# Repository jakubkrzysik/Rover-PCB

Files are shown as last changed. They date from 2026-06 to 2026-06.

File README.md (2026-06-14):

# Projekt PCB dla Łazika (Rover-PCB)

Repozytorium zawiera projekt płytki drukowanej w programie **KiCad 9.0** dla autonomicznego lub zdalnie sterowanego łazika (Rover). 

Projekt składa się z **dwóch fizycznych płytek** zaprojektowanych na jednym schemacie (`Rover_PCB.kicad_sch`) i w dwóch osobnych plikach PCB (`Rover_PCB.kicad_pcb` oraz `Rover_PCB _Power.kicad_pcb`), które łączą się ze sobą za pomocą złącza ATX oraz taśm FFC (Flat Flexible Cable).

---

## Główny Mikrokontroler

Sercem układu sterowania jest potężny mikrokontroler:
* **Model:** `STM32H743VITx` (obudowa LQFP-100)
* **Rdzeń:** ARM Cortex-M7 o taktowaniu do 480 MHz
* **Lokalizacja:** Lewa płytka (Main Board)

---

## Podział na Płytki

Projekt składa się z dwóch osobnych płytek drukowanych:

1. **Płytka Główna (Main Control & Driver Board - `Rover_PCB.kicad_pcb`):**
   * Zawiera mikrokontroler STM32H7,
   * Przetworniki analogowo-cyfrowe ADC `HX711` do pomiaru wagi (belek tensometrycznych),
   * Filtry i transceivery magistrali CAN (`SN65HVD230`),
   * Dwa zintegrowane sterowniki mostkowe H dla silników szczotkowych prądu stałego (`VNH5019A-E`),
   * Główne stabilizatory napięć (`AMS1117-3.3` o wydajności do 800 mA dla logiki, `LM2596S-5` o wydajności do 3 A dla linii 5V oraz `LM2596S-12` o wydajności do 3 A dla linii 12V),
   * Porty wejściowe zasilania wysokoprądowego (`XT90` 24V i 48V) oraz bezpośrednie złącza interfejsowe kontrolera (USB-C, RJ45),
   * **Układy MOSFET (low-side):** 10 kluczy MOSFET (2x IRLZ44N w obudowie TO-220 oraz 8x AO3400A w obudowie SOT-23) służących do kluczowania masy dla oświetlenia zewnętrznego, diody statusowej RGY oraz buzzera.

2. **Płytka Zasilania i Interfejsów (Power Distribution & Interface Board - `Rover_PCB _Power.kicad_pcb`):**
   * Działa jako panel dystrybucji zasilania i hub połączeń interfejsów,
   * Posiada złącza silników, serwomechanizmów, interfejsów komunikacyjnych (Magistrala CAN, UART), czujników temperatury (NTC) oraz wejścia belek tensometrycznych (Load Cells),
   * Dystrybuuje zasilanie przez złącza wysokoprądowe `XT60` i `XT30` o napięciach: 12V, 24V oraz 48V,
   * Zawiera diody LED oświetlenia zewnętrznego, wielokolorową diodę statusową RGY, buzzer oraz fizyczne porty do programowania (ST-LINK) i przycisk awaryjny (Safety Button).

### Połączenia Międzypłytkowe (Inter-board Connections)
Tablice łączą się ze sobą bezpośrednio za pomocą czterech mostków kablowych:
* **ATX (J45 na Głównej $\leftrightarrow$ J48 na Zasilania):** Złącze Molex Mini-Fit Jr 24-pin przesyłające główne szyny zasilające (3.3V, 5V, 12V, 24V, 48V, GND), wyjścia prądowe sterowników silników (`OUTA1`/`OUTB1`, `OUTA2`/`OUTB2`) oraz linie sterowania oświetleniem przednim LED (`PC6_OUT` i `PB9_OUT`).
* **FFC 30-pin (J46 na Głównej $\leftrightarrow$ J49 na Zasilania):** Przesyłanie sygnałów logicznych (sygnały PWM serw, interfejsy UART, linie CAN, sygnały pomiarowe z HX711) oraz linii sterowania tylnym oświetleniem LED, diodą statusową i buzzerem (`PB0_OUT`, `PB1_OUT`, `PB5_OUT`, `PB8_OUT`, `PC7_OUT`, `PC8_OUT`, `PC9_OUT`, `PC10_OUT`).
* **FFC 20-pin (J47 na Głównej $\leftrightarrow$ J50 na Zasilania):** Przesyłanie sygnałów z pozostałych belek tensometrycznych oraz linii pomiarowych czujników temperatury NTC.
* **FFC 6-pin (J72 na Głównej $\leftrightarrow$ J71 na Zasilania):** Przedłużenie złącza programatora ST-LINK (SWD) na płytkę zasilania, co umożliwia debugowanie i programowanie urządzenia poprzez wyprowadzone tam złącze `J37` bez konieczności rozpinania konstrukcji.

---

## Specyfikacja Złączy

Poniższa lista opisuje przeznaczenie wszystkich złączy na obu płytkach oraz sposób sterowania powiązanymi urządzeniami.

### 1. Płytka Główna (Sterowanie i Sterowniki - `Rover_PCB.kicad_pcb`)

| Złącze | Nazwa w schemacie | Typ Złącza | Przeznaczenie |
| :--- | :--- | :--- | :--- |
| **J1** | `XT90_24V_IN` | XT90 (Męskie, kątowe) | Główne wejście zasilania 24V z akumulatora (zabezpieczone bezpiecznikiem F1 - 15A). Zasila regulatory step-down (5V, 12V) oraz mostki silników VNH5019A-E. |
| **J35** | `XT90_48V_IN` | XT90 (Męskie, kątowe) | Wejście wysokiego napięcia zasilania 48V do celów dystrybucyjnych (zabezpieczone bezpiecznikiem F2 - 1A na odczepie pomiarowym). |
| **J43** | `XT90_24V_OUT` | XT90 (Męskie, kątowe) | Wyjście zasilania 24V (przelotka bezpośrednia z J1). |
| **J44** | `XT90_48V_OUT` | XT90 (Męskie, kątowe) | Wyjście zasilania 48V (przelotka bezpośrednia z J35). |
| **J19** | `RJ45` | RJ45 | Złącze interfejsu sieciowego. **Uwaga:** Piny 1 i 2 są połączone z wyjściami mostka H Brushed_Motor2 (`OUTA2`/`OUTB2`), a piny 3 i 4 z zasilaniem 5V/GND, co umożliwia sterowanie zewnętrznym silnikiem lub modułem za pomocą kabla Ethernet. |
| **J38** | `USB_C_Receptacle` | USB-C 16-pin | Port USB-C podłączony bezpośrednio do linii D+/D- mikrokontrolera (komunikacja USB 2.0). |
| **J45** | `ATX` | Molex Mini-Fit Jr 2x12 | Interfejs zasilania, mostków silnikowych oraz przedniego oświetlenia, łączący z płytką zasilania. |
| **J46** | `FFC_30` | FFC Socket 30-pin (1.0mm) | Port taśmy sygnałowej i oświetlenia tylnego/statusowego, łączący z płytką zasilania. |
| **J47** | `FFC_20` | FFC Socket 20-pin (1.0mm) | Port taśmy sygnałowej dla belek tensometrycznych i czujników NTC, łączący z płytką zasilania. |
| **J72** | `FFC_6` | FFC Socket 6-pin (1.0mm) | Port taśmy interfejsu SWD (ST-LINK), łączący z płytką zasilania. |
| **J75** | `TEST_PAD 5V` | Pad testowy (1.5mm) | Punkt testowy napięcia 5V na płytce głównej. |
| **J76** | `TEST_PAD GND` | Pad testowy (1.5mm) | Punkt testowy masy (GND) na płytce głównej. |
| **J77** | `TEST_PAD 24V` | Pad testowy (1.5mm) | Punkt testowy napięcia 24V na płytce głównej. |
| **J78** | `TEST_PAD 3.3V` | Pad testowy (1.5mm) | Punkt testowy napięcia 3.3V na płytce głównej. |
| **J79** | `TEST_PAD 12V` | Pad testowy (1.5mm) | Punkt testowy napięcia 12V na płytce głównej. |

### 2. Płytka Zasilania (Złącza Wykonawcze i Dystrybucja Zasilania - `Rover_PCB _Power.kicad_pcb`)

#### Złącza Połączeniowe z Płytką Główną:
* **J48:** ATX (Molex Mini-Fit 24-pin) - interfejs szyn zasilających i wyjść silników szczotkowych/oświetlenia przedniego
* **J49:** FFC 30-pin - główna taśma sygnałowa (sterowanie serw, UART, CAN, ADCs, oświetlenie tylne/statusowe)
* **J50:** FFC 20-pin - pomocnicza taśma sygnałowa (belki tensometryczne, sensory NTC)
* **J71:** FFC 6-pin - taśma interfejsu programowania SWD (ST-LINK)

#### Port Programatora i Debuggera:
* **J37 (`STLINK`):** Złącze kołkowe 1x05 na płytce zasilania służące do bezpośredniego podpięcia programatora SWD bez konieczności rozkręcania obudowy łazika. Sygnały: `+3.3V`, `GND`, `SWDIO`, `SWCLK`, `NRST`.

#### Sterowanie Silnikami Szczotkowymi (DC Brushed Motors):
Oba złącza silników są zasilane za pośrednictwem złącza ATX z lewej płytki, gdzie zainstalowane są dedykowane układy H-bridge **VNH5019A-E** (obsługujące prąd ciągły do 12A/szczytowo 30A).
* **J2 (`Brushed_Motor1`):** Podłączenie silnika DC 1 (Linie `/OUTA1` i `/OUTB1` ze sterownika U5).
* **J3 (`Brushed_Motor2`):** Podłączenie silnika DC 2 (Linie `/OUTA2` i `/OUTB2` ze sterownika U6).

#### Serwomechanizmy (Servo Outputs):
Złącza 3-pinowe (GND, zasilanie +5V z LM2596, sygnał PWM) służące do pozycjonowania ramion, chwytaków bądź kamer. Sterowanie odbywa się bezpośrednio za pomocą wbudowanych w STM32 układów zegarowych (Timer PWM):
* **J20 (`Servo1`):** Sterowanie PWM z pinu **`PE9`** (TIM1_CH1)
* **J21 (`Servo2`):** Sterowanie PWM z pinu **`PE11`** (TIM1_CH2)
* **J22 (`Servo3`):** Sterowanie PWM z pinu **`PE13`** (TIM1_CH3)
* **J23 (`Servo4`):** Sterowanie PWM z pinu **`PE14`** (TIM1_CH4)
* **J24 (`Servo5`):** Sterowanie PWM z pinu **`PD14`** (TIM4_CH3)
* **J25 (`Servo6`):** Sterowanie PWM z pinu **`PD15`** (TIM4_CH4)
* **J26 (`Servo7`):** Sterowanie PWM z pinu **`PA6`** (TIM3_CH1)
* **J27 (`Servo8`):** Sterowanie PWM z pinu **`PA7`** (TIM3_CH2)

#### Magistrala CAN (CAN Bus Distribution):
Na płytce zintegrowano magistralę CAN, co pozwala na łączenie urządzeń zewnętrznych (np. sterowników silników BLDC, enkoderów, sensorów). Wszystkie te złącza dzielą wspólne linie `/CANH` i `/CANL` obsługiwane przez transceivery `SN65HVD230` z lewej płytki.
Złącza są typu JST EH 4-pin (GND, CANH, CANL, zasilanie) o różnych napięciach na pinie zasilającym:
* **J11 - J15 (`CAN_S1 - CAN_S5`):** Linia zasilająca podłączona do napięcia **`+12V`**.
* **J16 - J17 (`CAN_S6 - CAN7`):** Linia zasilająca podłączona do napięcia **`+24V`**.
* **J18 (`CAN8`):** Linia zasilająca podłączona do napięcia **`+48V`** (dla najbardziej obciążonych/zewnętrznych modułów).

#### Złącza Komunikacji UART:
* **J28 (`UART1`):** Podłączone do portu UART1 mikrokontrolera (linie `/TX1` i `/RX1`, zasilanie `+5V`, `GND`).
* **J29 (`UART2`):** Podłączone do portu UART2 mikrokontrolera (linie `/TX2` i `/RX2`, zasilanie `+5V`, `GND`).

#### Czujniki Belki Tensometrycznej (Load Cells):
Układ obsługuje do 4 czujników nacisku/wagi. Każde złącze to standardowe wyprowadzenie 4-pinowe (zasilanie analogowe AVDD, różnicowe wejścia sygnałowe INA+/INA- oraz GND). Pomiary są filtrowane i cyfryzowane przez przetworniki HX711 (U9-U12) znajdujące się na lewej płytce.
* **J39 (`Load_Cell1`):** Podłączone do przetwornika `U9` (linie `/AVDD`, `/INA+`, `/INA-` przesyłane przez FFC 30-pin).
* **J40 (`Load_Cell2`):** Podłączone do przetwornika `U10` (linie `/AVDD1`, `/INA1+`, `/INA1-` przesyłane przez FFC 30-pin).
* **J41 (`Load_Cell3`):** Podłączone do przetwornika `U11` (linie `/AVDD2`, `/INA2+`, `/INA2-` przesyłane przez FFC 20-pin).
* **J42 (`Load_Cell4`):** Podłączone do przetwornika `U12` (linie `/AVDD3`, `/INA3+`, `/INA3-` przesyłane przez FFC 20-pin).

#### Czujniki Temperatury NTC:
Służą do monitorowania temperatury krytycznych elementów konstrukcji (akumulatory, silniki). Termistory NTC tworzą dzielnik napięcia (zasilanie +3.3V, wyjście na ADC i GND). Pomiar odbywa się bezpośrednio za pomocą kanałów przetwornika ADC mikrokontrolera STM32:
* **J51 (`NTC1`):** Podłączony do pinu analogowego **`PC0`** (przez FFC)
* **J52 (`NTC2`):** Podłączony do pinu analogowego **`PC1`** (przez FFC)
* **J53 (`NTC3`):** Podłączony do pinu analogowego **`PC2`** (przez FFC)
* **J54 (`NTC4`):** Podłączony do pinu analogowego **`PC3`** (przez FFC)

#### Diody Sygnalizacyjne LED (Oświetlenie / Status):
Wszystkie diody LED znajdują się na płytce zasilania. Są zasilane z napięcia +12V (oświetlenie zewnętrzne) lub +24V (dioda statusowa J10) i sterowane od strony masy (low-side) za pomocą kluczy MOSFET typu N zlokalizowanych na płytce głównej:

* **Oświetlenie Przednie (Klucze MOSFET THT - IRLZ44N w obudowie TO-220):**
  * **J8 (`LED_F_R` - Przód Prawy):** Sterowane z pinu **`PB9`** (klucz Q5, sygnał `PB9_OUT`)
  * **J9 (`LED_F_L` - Przód Lewy):** Sterowane z pinu **`PC6`** (klucz Q6, sygnał `PC6_OUT`)

* **Oświetlenie Tylne (Klucze MOSFET SMD - AO3400A w obudowie SOT-23):**
  * **J4 (`LED_R_LL` - Tylny Lewy Zewnętrzny):** Sterowane z pinu **`PB0`** (klucz Q15, sygnał `PB0_OUT`)
  * **J5 (`LED_R_LR` - Tylny Lewy Wewnętrzny):** Sterowane z pinu **`PB1`** (klucz Q14, sygnał `PB1_OUT`)
  * **J6 (`LED_R_RR` - Tylny Prawy Zewnętrzny):** Sterowane z pinu **`PB5`** (klucz Q13, sygnał `PB5_OUT`)
  * **J7 (`LED_R_RL` - Tylny Prawy Wewnętrzny):** Sterowane z pinu **`PB8`** (klucz Q12, sygnał `PB8_OUT`)

* **Sygnalizacja Systemowa (Klucze MOSFET SMD - AO3400A w obudowie SOT-23):**
  * **J10 (`LED_RGY_B` - Trójkolorowa dioda statusu RGY + Buzzer):** Złącze zasilane z napięcia +24V, sterowane z czterech pinów:
    * Pin **`PC7`** (kolor czerwony LED - klucz Q11, sygnał `PC7_OUT`)
    * Pin **`PC8`** (kolor zielony LED - klucz Q16, sygnał `PC8_OUT`)
    * Pin **`PC9`** (kolor żółty LED - klucz Q17, sygnał `PC9_OUT`)
    * Pin **`PC10`** (Buzzer - klucz Q18, sygnał `PC10_OUT`)

#### Dystrybucja Zasilania Zewnętrznego (Power Distribution Ports):
Wyjścia zasilania służą do zasilania urządzeń o dużym poborze prądu.
* **Szyna 24V:**
  * `J55`, `J56`, `J57`, `J58` (złącza XT60)
  * `J59`, `J60`, `J61`, `J62` (złącza XT30)
* **Szyna 48V:**
  * `J63`, `J64` (złącza XT60)
  * `J67`, `J68` (złącza XT30)
* **Szyna 12V** (zasilana ze stabilizatora LM2596S-12):
  * `J65`, `J66` (złącza XT60)
  * `J69`, `J70` (złącza XT30)
* **Złącza Śrubowe (Terminal Blocks):**
  Umożliwiają bezpośrednie wyprowadzenie stałego napięcia (VOUT i GND) dla mniejszych odbiorników:
  * `J30` -> 3.3V
  * `J31` -> 5.0V (ze stabilizatora LM2596S-5)
  * `J32` -> 12.0V (ze stabilizatora LM2596S-12)
  * `J33` -> 24.0V (bezpośrednio z XT90_24V_IN)
  * `J34` -> 48.0V (bezpośrednio z XT90_48V_IN)

#### Monitoring Akumulatora (Battery Measurement):
* **J73 (`BAT1`):** Podłączenie pojedynczej celi / baterii do monitorowania napięcia.
* **J74 (`BAT_TOTAL`):** Podłączenie pełnego pakietu do monitorowania sumarycznego napięcia.
* **J36 (`Safety_Button`):** Złącze pod przycisk awaryjny (np. grzybek E-STOP), podłączone do pinu **`PE15`** mikrokontrolera STM32.

---

## Parametry Fizyczne PCB i Klasy Połączeń

Obie płytki w projekcie (Płytka Główna oraz Płytka Zasilania) zostały zaprojektowane z określonym stackupem i regułami szerokości połączeń w programie KiCad.

### 1. Ułożenie Warstw (Stackup)
Płytka Główna (`Rover_PCB.kicad_pcb`) oraz Płytka Zasilania (`Rover_PCB _Power.kicad_pcb`) posiadają identyczny, profesjonalny **4-warstwowy** stackup o łącznej grubości laminatu **1.6 mm** ze standardową grubością miedzi **35 µm (1 oz)** na wszystkich warstwach miedzianych:
* **F.Cu (Top)** — Zewnętrzna górna warstwa sygnałowa/mieszana.
* **In1.Cu (Internal 1)** — Wewnętrzna warstwa sygnałowo-zasilająca.
* **In2.Cu (Internal 2)** — Wewnętrzna dedykowana warstwa zasilania (szyna power).
* **B.Cu (Bottom)** — Zewnętrzna dolna warstwa sygnałowa/mieszana.

Dielektryk między warstwami zewnętrznymi a wewnętrznymi stanowi prepreg FR4 o grubości **0.1 mm**, a rdzeń wewnętrzny (core) ma grubość **1.24 mm**.

### 2. Klasy Netów (Net Classes)
W obu projektach skonfigurowano analogiczne dedykowane klasy połączeń dopasowane do obciążalności prądowej oraz typu sygnałów:

| Klasa Połączeń | Szerokość ścieżki | Odstęp (Clearance) | Średnica przelotki | Wiercenie przelotki | Zastosowanie / Przypisane Połączenia |
| :--- | :---: | :---: | :---: | :---: | :--- |
| **`Default`** | **0.20 mm** | 0.20 mm | 0.60 mm | 0.30 mm | Sygnały logiczne mikrokontrolera, GPIO, szyna `/+3.3V` |
| **`CAN`** | **0.25 mm** | 0.20 mm | 0.60 mm | 0.30 mm | Różnicowe linie magistrali CAN (`/CANH`, `/CANL`, `/CANH_ETH`, `/CANL_ETH`) |
| **`GND`** | **0.50 mm** | 0.20 mm | 0.80 mm | 0.40 mm | Masa główna układu (`/GND`) |
| **`Power10A`** | **4.00 mm** | 0.30 mm | 1.50 mm | 0.80 mm | Główna szyna wysokoprądowa zasilania `/+48V` |
| **`Power5A`** | **2.00 mm** | 0.30 mm | 1.20 mm | 0.60 mm | Szyny zasilania `/+12V` oraz `/+24V` |
| **`Power1A`** | **0.50 mm** | 0.20 mm | 0.80 mm | 0.40 mm | Szyna zasilania logiki `/+5V` |
| **`USB_FS`** | **0.20 mm** | 0.15 mm | 0.60 mm | 0.30 mm | Sygnały różnicowe portu USB-C (`/D-`, `/D+`) |

### 3. Trasowanie i Szerokości Ścieżek na Płytkach

#### A. Płytka Główna (`Rover_PCB.kicad_pcb`)
* **Trasy wysokoprądowe:** Wytrasowane z szerokościami **4.00 mm** (linia `+48V`) oraz **2.00 mm** (linie `+12V` i `+24V`).
* **Zasilanie logiki i masa:** Wytrasowane szerokością **0.50 mm** (dystrybucja masy `/GND` oraz szyna `+5V`).
* **Sygnały CAN:** Szerokość ścieżek wynosi **0.25 mm**.
* **Sygnały domyślne:** Ścieżki sygnałowe mikrokontrolera STM32 mają szerokość **0.20 mm**.
* **Ścieżki niestandardowe (Custom/Ręczne):**
  * **0.10 mm** (5 segmentów) – użyte w linii **`/RX2`** na warstwie górnej w celu wyprowadzenia trasy z gęstego obszaru wyprowadzeń MCU.
  * **1.00 mm** (5 segmentów) – użyte lokalnie w masie `/GND` oraz w linii `Net-(J1-Pin_1)`.
  * **1.1018 mm** oraz **1.5998 mm** – lokalne przewężenia (neckdown) na linii zasilania `+24V`.

#### B. Płytka Zasilania (`Rover_PCB _Power.kicad_pcb`)
* **Trasy wysokoprądowe:** Wytrasowane z szerokościami **4.00 mm** (linia `+48V` - 25 segmentów) oraz **2.00 mm** (linie `+12V` - 64 segmenty, `+24V` - 43 segmenty, `+48V` - 6 segmentów).
* **Zasilanie logiki i masa:** Wytrasowane szerokością **0.50 mm** (dystrybucja linii `/GND` - 19 segmentów oraz szyna `+5V` - 22 segmenty).
* **Sygnały CAN:** Wytrasowane ścieżkami o szerokości **0.25 mm** (łącznie 73 segmenty dla `/CANH` i `/CANL`).
* **Sygnały domyślne:** Wytrasowane ścieżkami o szerokości **0.20 mm** (łącznie 397 segmentów).
* **Ścieżki niestandardowe i przewężenia (Custom/Ręczne):**
  * **1.6998 mm** (3 segmenty) – w liniach `+12V` oraz `+48V`.
  * **1.7018 mm** (2 segmenty) – w linii `+12V`.
  * **2.6998 mm** (2 segmenty) – w linii `+48V`.
  * *Uwaga: Główne przesyłanie wysokich prądów na Płytce Zasilania jest dodatkowo wspierane przez rozległe wylewki miedziane (zones) na warstwach zewnętrznych i wewnętrznych.*

---

## Wykaz Części (BOM) do Złożenia Płytki

Poniższa tabela zawiera kompletny wykaz wszystkich elementów niezbędnych do zmontowania płytek (Płytki Głównej oraz Płytki Zasilania).
Każdy element został powiązany z konkretnym, pasującym footprintem w programie KiCad, co gwarantuje poprawność montażu po zakupie.

| Lp. | Oznaczenia na schemacie (Ref) | Wartość/Nazwa | Obudowa / Nazwa Footprintu (KiCad) | Sugerowany Numer Części (MPN) | Opis / Uwagi | Ilość |
| :--- | :--- | :--- | :--- | :--- | :--- | :--- |
| 1 | D4, D5 | D_Zener | `DO-201 (THT, raster 12.7 mm)` | **1N5349BG** | Dioda Zenera 12V, 5W | 2 |
| 2 | D1, D2 | 1N5822 | `DO-201AD (THT, raster 15.24 mm)` | **1N5822-E3/54** | Dioda Schottky 40V, 3A (THT) | 2 |
| 3 | U2 | AMS1117-3.3 | `SOT-223-3` | **AMS1117-3.3** | Stabilizator liniowy LDO 3.3V, 1A | 1 |
| 4 | Q11, Q12, Q13, Q14, Q15, Q16, Q17, Q18 | AO3400A | `SOT-23 (SMD)` | **AO3400A** | Tranzystor N-MOSFET (30V, 5.7A, Rds=19mOhm) | 8 |
| 5 | J59, J60, J61, J62, J67, J68, J69, J70 | XT30_12V_OUT | `Amass XT30U-F (pionowe żeńskie PCB)` | **Amass XT30U-F** | Złącze wysokoprądowe XT30 żeńskie pionowe na płytkę | 8 |
| 6 | J55, J56, J57, J58, J63, J64, J65, J66 | XT60_24V_OUT | `Amass XT60-M (pionowe męskie PCB)` | **Amass XT60-M** | Złącze wysokoprądowe XT60 męskie pionowe na płytkę | 8 |
| 7 | J1, J35, J43, J44 | XT90_48V_OUT | `Amass XT90PW-M (kątowe męskie PCB)` | **Amass XT90PW-M** | Wysokoprądowe złącze XT90 męskie kątowe na płytkę | 4 |
| 8 | J38 | USB_C_Receptacle_USB2.0_16P | `USB-C 16-pin GCT USB4105 (poziome)` | **GCT USB4105-GF-A** | Gniazdo USB 2.0 typu C, 16-pin, montaż mieszany SMT+THT | 1 |
| 9 | U9, U10, U11, U12 | HX711 | `SOIC-16 (szerokość 3.9 mm, raster 1.27 mm)` | **HX711** | 24-bitowy przetwornik ADC dla belek tensometrycznych | 4 |
| 10 | Q5, Q6 | IRLZ44N | `TO-220-3 (pionowy)` | **IRLZ44NPBF** | Tranzystor N-MOSFET logic-level (55V, 47A, Rds=22mOhm) | 2 |
| 11 | J2, J3, J4, J5, J6, J7, J8, J9, J36, J73, J74 | LED_R_RL | `JST EH 2-pin vertical (raster 2.50 mm)` | **JST B2B-EH-A(LF)(SN)** | Złącze JST serii EH, 2-pinowe pionowe męskie | 11 |
| 12 | J51, J52, J53, J54 | NTC1 | `JST EH 3-pin vertical (raster 2.50 mm)` | **JST B3B-EH-A(LF)(SN)** | Złącze JST serii EH, 3-pinowe pionowe męskie | 4 |
| 13 | J11, J12, J13, J14, J15, J16, J17, J18, J28, J29, J39, J40, J41, J42 | CAN7 | `JST EH 4-pin vertical (raster 2.50 mm)` | **JST B4B-EH-A(LF)(SN)** | Złącze JST serii EH, 4-pinowe pionowe męskie | 14 |
| 14 | J10 | LED_RGY_B | `JST EH 5-pin vertical (raster 2.50 mm)` | **JST B5B-EH-A(LF)(SN)** | Złącze JST serii EH, 5-pinowe pionowe męskie | 1 |
| 15 | U4 | LM2596S-12 | `TO-263-5 (D2PAK)` | **LM2596S-12/NOPB** | Przetwornica obniżająca step-down impulsowa 12V, 3A | 1 |
| 16 | U3 | LM2596S-5 | `TO-263-5 (D2PAK)` | **LM2596S-5.0/NOPB** | Przetwornica obniżająca step-down impulsowa 5V, 3A | 1 |
| 17 | F1 | 15A | `Bezpiecznik samochodowy Mini Blade (lutowany w płytkę)` | **Littelfuse 0297015.WXNV + uchwyt Littelfuse 01530007Z** | Bezpiecznik Mini Blade 15A z uchwytem lutowanym | 1 |
| 18 | F2 | 1A | `Littelfuse 395 Series (raster 5.08 mm)` | **Littelfuse 39511000000** | Bezpiecznik miniaturowy TR5 1A, zwłoczny | 1 |
| 19 | Taśma-FFC-6 | Taśma FFC 6-pin | `Taśma FFC 6-pin (raster 1.0 mm, dł. 152 mm, typ A)` | **Molex 15167-0211 (lub zamiennik 6-pin, raster 1.0mm)** | Elastyczny przewód płaski FFC łączący gniazda J71 i J72 (linie SWD ST-Link) | 1 |
| 20 | Taśma-FFC-20 | Taśma FFC 20-pin | `Taśma FFC 20-pin (raster 1.0 mm, dł. 152 mm, typ A)` | **Molex 15167-0355 (lub zamiennik 20-pin, raster 1.0mm)** | Elastyczny przewód płaski FFC łączący gniazda J47 i J50 | 1 |
| 21 | Taśma-FFC-30 | Taśma FFC 30-pin | `Taśma FFC 30-pin (raster 1.0 mm, dł. 152 mm, typ A)` | **Molex 15167-0487 (lub zamiennik 30-pin, raster 1.0mm)** | Elastyczny przewód płaski FFC łączący gniazda J46 i J49 | 1 |
| 22 | J71, J72 | FFC | `FFC/FPC 6-pin, raster 1.00 mm (poziome)` | **Molex 200528-0060** | Gniazdo taśmy elastycznej FFC 6-pin, poziome SMT | 2 |
| 23 | J47, J50 | FFC | `FFC/FPC 20-pin, raster 1.00 mm (poziome)` | **Molex 200528-0200** | Gniazdo taśmy elastycznej FFC 20-pin, poziome SMT | 2 |
| 24 | J46, J49 | Conn_01x30_Socket | `FFC/FPC 30-pin, raster 1.00 mm (poziome)` | **Molex 200528-0300** | Gniazdo taśmy elastycznej FFC 30-pin, poziome SMT | 2 |
| 25 | J45, J48 | ATX | `Molex Mini-Fit Jr 5566-24A (2x12, raster 4.2 mm)` | **Molex 39-28-1243 (lub 39-28-8240)** | Złącze ATX 24-pin pionowe męskie | 2 |
| 26 | L1, L2 | 30u | `MS42 (SMD, Neosid Ms42)` | **Neosid MS42 30uH** | Dławik/cewka indukcyjna SMD 30µH | 2 |
| 27 | J19 | RJ45 | `RJ45 Jack Ninigi GE` | **Ninigi RJ45-GE (lub Molex 95501-2881)** | Gniazdo Ethernet RJ45 8p8c THT | 1 |
| 28 | J37 | STLINK | `PinSocket 1x05 vertical, raster 2.54 mm` | **PPTC051LFBN-RC (Sullins)** | Gniazdo kołkowe (żeńskie) 1x5, raster 2.54mm | 1 |
| 29 | SW1 | SW_Push | `Tactile Switch 6x6 mm, wys. 4.3 mm (THT)` | **PTS645TL43-2 LFS** | Przycisk monostabilny (tact switch) THT | 1 |
| 30 | C5, C6 | 2.2u | `Radialny THT (Ø4.0 mm, raster 1.50 mm)` | **Panasonic ECE-A1HN2R2UB** | Kondensator elektrolityczny bipolarny 2.2µF, 50V | 2 |
| 31 | C1, C2, C3, C4 | 220u | `Radialny THT (Ø5.0 mm, raster 2.50 mm)` | **Panasonic EEU-FR1E221** | Kondensator elektrolityczny niskoimpedancyjny 220µF, 25V | 4 |
| 32 | J30, J31, J32, J33, J34 | 48V | `Phoenix MKDS-1.5-2 (raster 5.08 mm)` | **Phoenix Contact 1715721 (MKDS 1,5/2-5,08)** | Złącze śrubowe (terminal block) 2-pin do druku | 5 |
| 33 | J20, J21, J22, J23, J24, J25, J26, J27 | Servo8 | `PinHeader 1x03 vertical, raster 2.54 mm` | **Pin Header 1x03 vertical (2.54mm pitch)** | Listwa kołkowa (goldpin) 1x3, raster 2.54mm | 8 |
| 34 | R1, R4, R5, R6, R7, R8, R9, R10, R11, R12, R13, R14, R15, R16, R22 | 10k | `SMD 0603 (1608 Metric)` | **RC0603FR-0710KL** | Rezystor SMD 0603, tolerancja 1%, wartość 10k | 15 |
| 35 | R17-Terminator1 | 120 | `SMD 0603 (1608 Metric)` | **RC0603FR-07120RL** | Rezystor SMD 0603, tolerancja 1%, wartość 120 | 1 |
| 36 | R17 | 330 | `SMD 0603 (1608 Metric)` | **RC0603FR-07330RL** | Rezystor SMD 0603, tolerancja 1%, wartość 330 | 1 |
| 37 | R19, R21 | 3.9k | `SMD 0603 (1608 Metric)` | **RC0603FR-073K9L** | Rezystor SMD 0603, tolerancja 1%, wartość 3.9k | 2 |
| 38 | R18, R20 | 47k | `SMD 0603 (1608 Metric)` | **RC0603FR-0747KL** | Rezystor SMD 0603, tolerancja 1%, wartość 47k | 2 |
| 39 | R2, R3 | 5.1k | `SMD 0603 (1608 Metric)` | **RC0603FR-075K1L** | Rezystor SMD 0603, tolerancja 1%, wartość 5.1k | 2 |
| 40 | D6 | SD36_SOD323 | `SOD-323 (SMD)` | **SD36-01FTG** | Dioda TVS jedno-kierunkowa 36V, obudowa SOD-323 | 1 |
| 41 | U7, U8 | SN65HVD230 | `SOIC-8 (szerokość 3.9 mm, raster 1.27 mm)` | **SN65HVD230D** | Transceiver CAN, zasilany napięciem 3.3V | 2 |
| 42 | U1 | STM32H743VITx | `LQFP-100 (14x14 mm, raster 0.5 mm)` | **STM32H743VIT6** | Mikrokontroler ARM Cortex-M7, 2MB Flash, 1MB RAM | 1 |
| 43 | U5, U6 | VNH5019A-E | `MultiPowerSO-30 (STMicroelectronics)` | **VNH5019ATR-E** | Mostek H - sterownik silników DC szczotkowych (30A/41V) | 2 |
| 44 | D3 | LED | `LED 5.0 mm (THT)` | **WP7113ID** | Dioda LED czerwona 5mm (THT) | 1 |
| 45 | C7, C8 | 10n | `SMD 0603 (1608 Metric)` | **Yageo CC0603KRX7R9BB103** | Kondensator ceramiczny MLCC SMD 0603 X7R 10nF 50V | 2 |
| 46 | C9, C10 | 18pF | `SMD 0603 (1608 Metric)` | **CC0603JRNPO9BN180** | Kondensator ceramiczny MLCC SMD 0603 NP0 18pF 50V (dla rezonatora Y2) | 2 |
| 47 | Y2 | 8MHz | `Crystal:Crystal_SMD_3225-4Pin_3.2x2.5mm_HandSoldering` | **NX3225GD-8.000M-STD-CRA-3** | Rezonator kwarcowy SMD 3.2x2.5mm (dla STM32H7) | 1 |

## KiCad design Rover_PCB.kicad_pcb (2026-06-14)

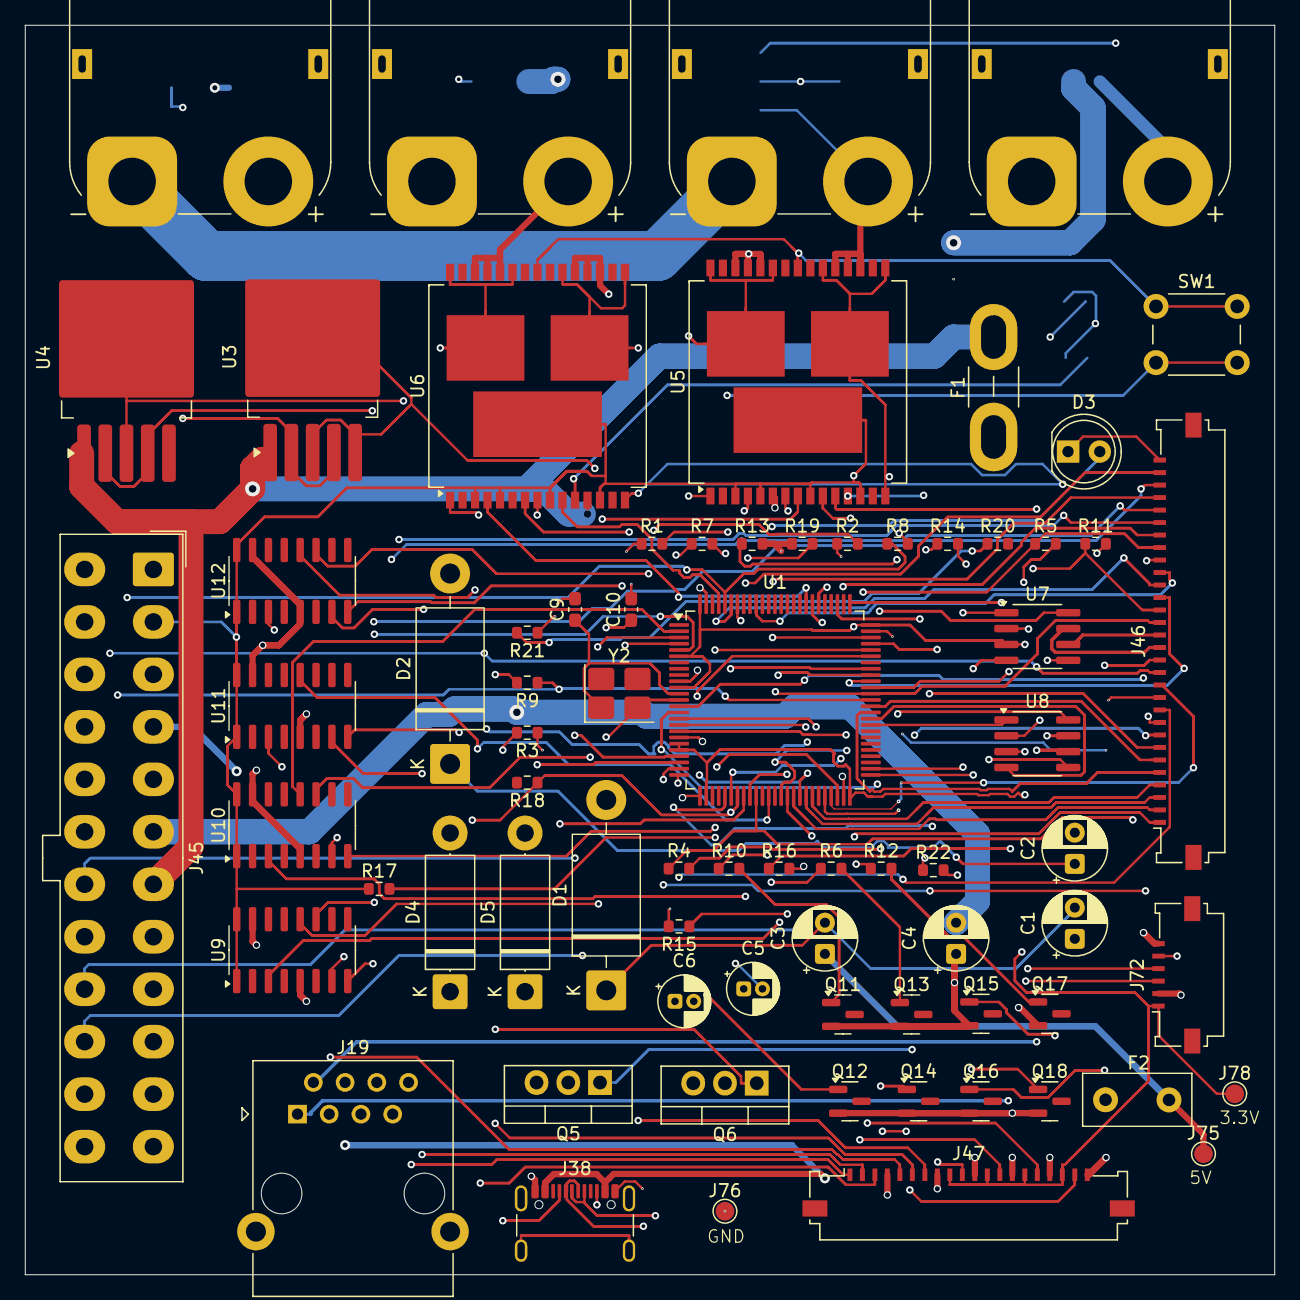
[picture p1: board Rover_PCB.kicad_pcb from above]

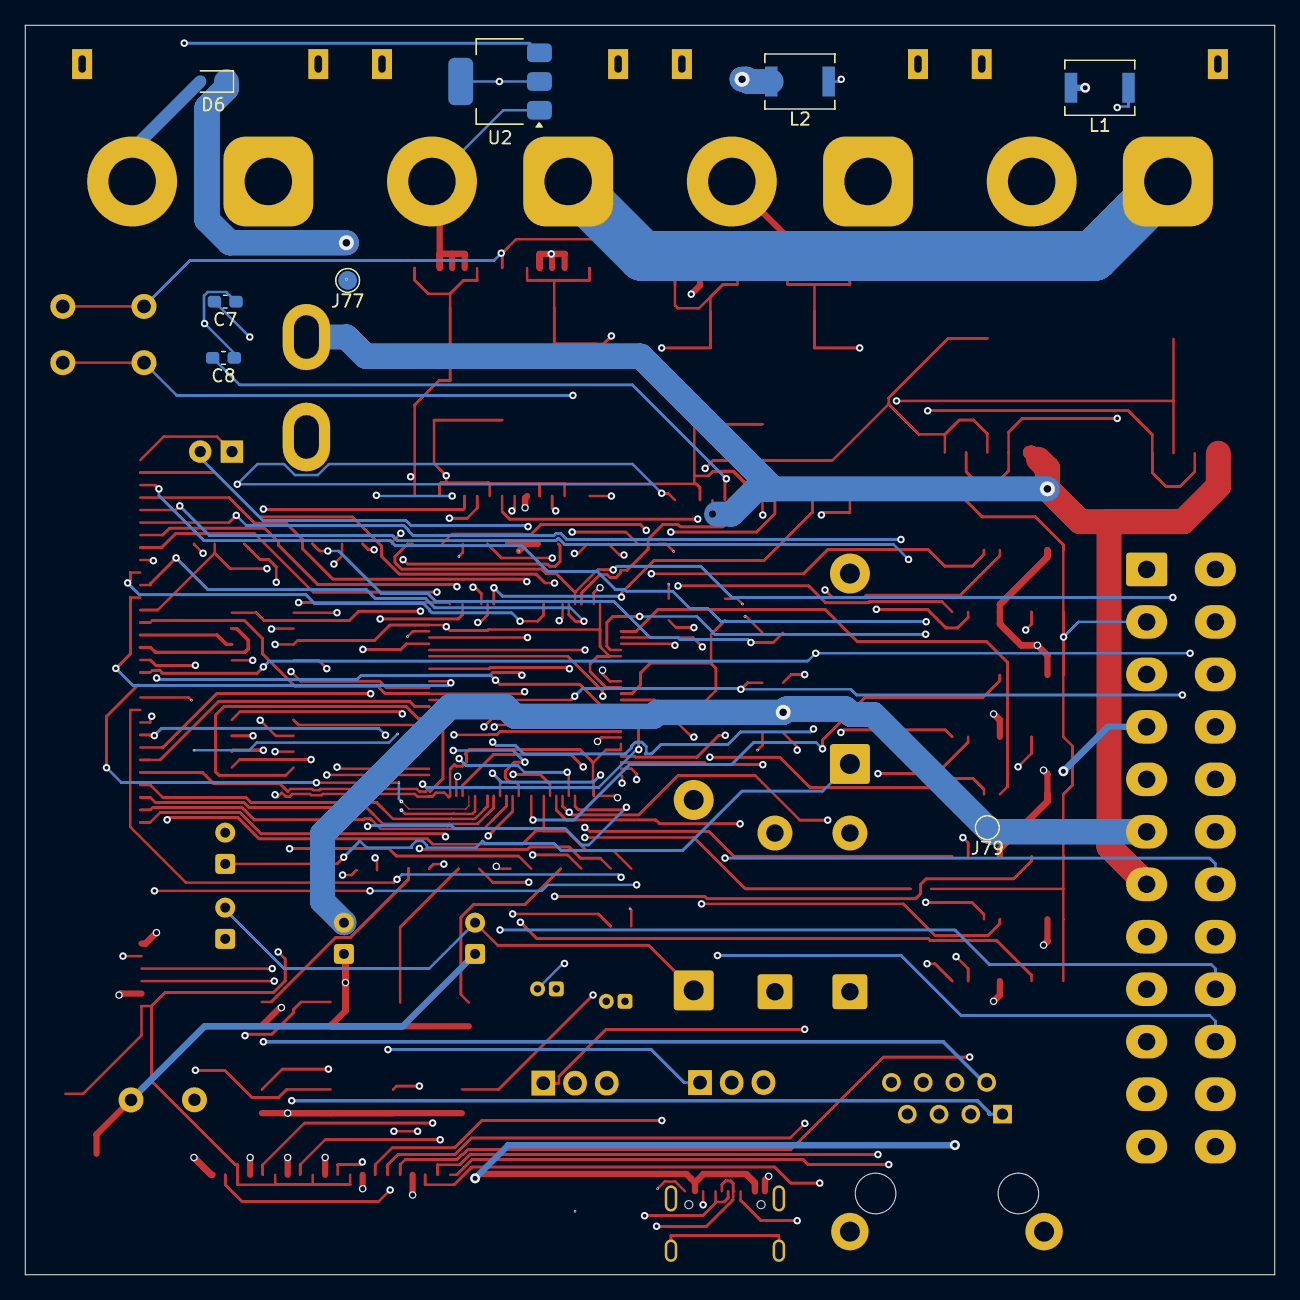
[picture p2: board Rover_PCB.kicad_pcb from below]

Board: 4 copper layers, 100.0 x 100.0 mm, 81 parts (8 on the bottom side), 108 nets.

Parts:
C1, C2, C3, C4: 220u; CP_Radial_D5.0mm_P2.50mm
C5, C6: 2.2u; CP_Radial_D4.0mm_P1.50mm
C7, C8: 10n; C_0603_1608Metric_Pad1.08x0.95mm_HandSolder
C9, C10: 18pF; C_0603_1608Metric_Pad1.08x0.95mm_HandSolder
D1, D2: 1N5822; D_DO-201AD_P15.24mm_Horizontal
D3: LED; LED_D5.0mm
D4, D5: D_Zener; D_5W_P12.70mm_Horizontal
D6: SD36_SOD323; D_SOD-323
F1: 15A; Fuse_Blade_Mini_directSolder
F2: 1A; Fuse_Littelfuse_395Series
J1: XT90_24V_IN; AMASS_XT90PW-M_1x02_P10.90mm_Horizontal
J19: RJ45; RJ45_Ninigi_GE
J35: XT90_48V_IN; AMASS_XT90PW-M_1x02_P10.90mm_Horizontal
J38: USB_C_Receptacle_USB2.0_16P; USB_C_Receptacle_GCT_USB4105-xx-A_16P_TopMnt_Horizontal
J43: XT90_24V_OUT; AMASS_XT90PW-M_1x02_P10.90mm_Horizontal
J44: XT90_48V_OUT; AMASS_XT90PW-M_1x02_P10.90mm_Horizontal
J45: ATX; Molex_Mini-Fit_Jr_5566-24A_2x12_P4.20mm_Vertical
J46: Conn_01x30_Socket; Molex_200528-0300_1x30-1MP_P1.00mm_Horizontal
J47: FFC; Molex_200528-0200_1x20-1MP_P1.00mm_Horizontal
J72: FFC; Molex_200528-0060_1x06-1MP_P1.00mm_Horizontal
J75: TEST_PAD 5V; TestPoint_Pad_D1.5mm
J76: TEST_PAD GND; TestPoint_Pad_D1.5mm
J77: TEST_PAD 24V; TestPoint_Pad_D1.5mm
J78: TEST_PAD 3.3V; TestPoint_Pad_D1.5mm
J79: TEST_PAD 12V; TestPoint_Pad_D1.5mm
L1, L2: 30u; L_Neosid_Ms42
Q5, Q6: IRLZ44N; TO-220-3_Vertical
Q11, Q12, Q13, Q14, Q15, Q16, Q17, Q18: AO3400A; SOT-23
R1, R4, R5, R6, R7, R8, R9, R10, R11, R12, R13, R14, R15, R16, R22: 10k; R_0603_1608Metric
R2, R3: 5.1k; R_0603_1608Metric
R17: 330; R_0603_1608Metric
R18, R20: 47k; R_0603_1608Metric
R19, R21: 3.9k; R_0603_1608Metric
SW1: SW_Push; SW_PUSH_6mm_H4.3mm
U1: STM32H743VITx; LQFP-100_14x14mm_P0.5mm
U2: AMS1117-3.3; SOT-223-3_TabPin2
U3: LM2596S-5; TO-263-5_TabPin3
U4: LM2596S-12; TO-263-5_TabPin3
U5, U6: VNH5019A-E; ST_MultiPowerSO-30
U7, U8: SN65HVD230; SOIC-8_3.9x4.9mm_P1.27mm
U9, U10, U11, U12: HX711; SOIC-16_3.9x9.9mm_P1.27mm
Y2: 8MHz; Crystal_SMD_3225-4Pin_3.2x2.5mm_HandSoldering

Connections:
/+3.3V: J45.2, J45.3, J47.9, J47.12, J47.15, J47.18, J72.1, J78.1, R17.1, SW1.1, U1.6 (VBAT), U1.11 (VDD), U1.20 (VREF+), U1.21 (VDDA), U1.27 (VDD), U1.50 (VDD), U1.75 (VDD), U1.100 (VDD), U2.2 (VO), U5.3 (VCC), U5.5 (EN/DIAGA), U5.9 (EN/DIAGB), U5.13 (VCC), U5.23 (VCC), U5.31 (VCC), U6.3 (VCC), U6.5 (EN/DIAGA), U6.9 (EN/DIAGB), U6.13 (VCC), U6.23 (VCC), U6.31 (VCC), U7.3 (VCC), U8.3 (VCC), U9.1 (VSUP), U9.16 (DVDD), U10.1 (VSUP), U10.16 (DVDD), U11.1 (VSUP), U11.16 (DVDD), U12.1 (VSUP), U12.16 (DVDD)
/+5V: C3.1, F2.2, J19.4, J38.A4 (VBUS), J38.A9 (VBUS), J38.B4 (VBUS), J38.B9 (VBUS), J45.4, J75.1, L1.2
/+12V: C4.2, J45.5, J45.6, J79.1, L2.2
/+24V: C1.1, C2.2, D6.1 (A1), F1.2, J43.1, J45.7, J45.8, J45.9, J77.1, U3.1 (VIN), U4.1 (VIN), U5.12 (VBAT), U6.12 (VBAT)
/+48V: J35.1, J44.1, J45.10, J45.11, J45.12, J45.13, J45.14
/AVDD: J46.24, U9.3 (AVDD)
/AVDD1: J46.27, U10.3 (AVDD)
/AVDD2: J47.1, U11.3 (AVDD)
/AVDD3: J47.5, U12.3 (AVDD)
/CANH: J46.15, U7.7 (CANH)
/CANH_ETH: J19.1, U8.7 (CANH)
/CANL: J46.16, U7.6 (CANL)
/CANL_ETH: J19.2, U8.6 (CANL)
/D+: J38.A6 (D+), J38.B6 (D+), U1.71 (PA12)
/D-: J38.A7 (D-), J38.B7 (D-), U1.70 (PA11)
/GND: C4.1, C5.1, C6.2, C7.1, C8.1, C9.2, C10.2, D1.2 (A), D2.2 (A), D3.1 (K), D4.2 (A), D5.2 (A), D6.2 (A2), J1.2, J19.3, J35.2, J38.A1 (GND), J38.A12 (GND), J38.B1 (GND), J38.B12 (GND), J43.2, J44.2, J45.1, J45.15, J45.16, J45.17, J45.18, J46.30, J47.4, J47.8, J47.11, J47.14, J47.17, J47.20, J72.2, J72.6, J76.1, Q5.3 (S), Q6.3 (S), Q11.2 (S), Q12.2 (S), Q13.2 (S), Q14.2 (S), Q15.2 (S), Q16.2 (S), Q17.2 (S), Q18.2 (S), R1.1, R2.1, R3.1, R13.2, R14.2, R15.2, R16.2, R19.1, R21.1, U1.10 (VSS), U1.19 (VSSA), U1.26 (VSS), U1.49 (VSS), U1.74 (VSS), U1.99 (VSS), U2.1 (GND), U5.6 (CS_DIS), U5.18 (GNDB), U5.19 (GNDB), U5.20 (GNDB), U5.26 (GNDA), U5.27 (GNDA), U5.28 (GNDA), U6.18 (GNDB), U6.19 (GNDB), U6.20 (GNDB), U6.26 (GNDA), U6.27 (GNDA), U6.28 (GNDA), U7.2 (GND), U8.2 (GND), U9.5 (AGND), U9.15 (RATE), U10.5 (AGND), U10.15 (RATE), U11.5 (AGND), U11.15 (RATE), U12.5 (AGND), U12.15 (RATE)
/INA1+: J46.29, U10.8 (INA+)
/INA1-: J46.28, U10.7 (INA-)
/INA2+: J47.3, U11.8 (INA+)
/INA2-: J47.2, U11.7 (INA-)
/INA3+: J47.7, U12.8 (INA+)
/INA3-: J47.6, U12.7 (INA-)
/INA+: J46.25, U9.8 (INA+)
/INA-: J46.26, U9.7 (INA-)
/NRST: J72.5, U1.14 (NRST)
/OUTA1: J45.22, U5.1 (OUTA), U5.25 (OUTA), U5.30 (OUTA), U5.33 (OUTA)
/OUTA2: J45.20, J46.13, U6.1 (OUTA), U6.25 (OUTA), U6.30 (OUTA), U6.33 (OUTA)
/OUTB1: J45.21, U5.15 (OUTB), U5.16 (OUTB), U5.21 (OUTB), U5.32 (OUTB)
/OUTB2: J45.19, J46.14, U6.15 (OUTB), U6.16 (OUTB), U6.21 (OUTB), U6.32 (OUTB)
/PA0: U1.22 (PA0), U5.8 (CS)
/PA1: U1.23 (PA1), U6.8 (CS)
/PA6: J46.7, U1.30 (PA6)
/PA7: J46.8, U1.31 (PA7)
/PA8: U1.67 (PA8), U5.7 (PWM)
/PA9: U1.68 (PA9), U6.7 (PWM)
/PB0: J46.23, R5.1, U1.34 (PB0)
/PB1: J46.22, R4.1, U1.35 (PB1)
/PB5: J46.21, R6.1, U1.91 (PB5)
/PB8: J46.20, R7.1, U1.95 (PB8)
/PB9: J45.24, R8.1, U1.96 (PB9)
/PB12: U1.51 (PB12), U7.4 (R)
/PB13: U1.52 (PB13), U7.1 (D)
/PC0: J47.10, U1.15 (PC0)
/PC1: J47.13, U1.16 (PC1)
/PC2: J47.16, U1.17 (PC2_C)
/PC3: J47.19, U1.18 (PC3_C)
/PC4: D4.1 (K), R18.1, R19.2, U1.32 (PC4)
/PC5: D5.1 (K), R20.1, R21.2, U1.33 (PC5)
/PC6: J45.23, R9.1, U1.63 (PC6)
/PC7: J46.17, R10.1, U1.64 (PC7)
/PC8: J46.18, R11.1, U1.65 (PC8)
/PC9: J46.19, R12.1, U1.66 (PC9)
/PC10: R22.1, U1.78 (PC10)
/PD0: U1.81 (PD0), U5.4 (INA)
/PD1: U1.82 (PD1), U5.10 (INB)
/PD2: U1.83 (PD2), U6.4 (INA)
/PD12: U1.59 (PD12), U8.1 (D)
/PD13: U1.60 (PD13), U8.4 (R)
/PD14: J46.5, U1.61 (PD14)
/PD15: J46.6, U1.62 (PD15)
/PE0: U1.97 (PE0), U6.10 (INB)
/PE3: U1.2 (PE3), U10.12 (DOUT)
/PE4: U1.3 (PE4), U10.11 (PD_SCK)
/PE5: U1.4 (PE5), U9.12 (DOUT)
/PE6: U1.5 (PE6), U9.11 (PD_SCK)
/PE7: U1.37 (PE7), U11.12 (DOUT)
/PE9: J46.1, U1.39 (PE9)
/PE10: U1.40 (PE10), U12.12 (DOUT)
/PE11: J46.2, U1.41 (PE11)
/PE12: U1.42 (PE12), U12.11 (PD_SCK)
/PE13: J46.3, U1.43 (PE13)
/PE14: J46.4, U1.44 (PE14)
/RX1: J46.10, U1.25 (PA3)
/RX2: J46.12, U1.47 (PB11)
/SWCLK: J72.4, U1.76 (PA14)
/SWDIO: J72.3, U1.72 (PA13)
/TX1: J46.9, U1.24 (PA2)
/TX2: J46.11, U1.46 (PB10)
unnamed: C5.2, U1.48 (VCAP)
unnamed: C6.1, U1.73 (VCAP)
unnamed: C1.2, C3.2, D1.1 (K), U3.3 (GND), U3.5 (~ON/OFF)
unnamed: C2.1, D2.1 (K), U4.3 (GND)
unnamed: D3.2 (A), R17.2
unnamed: F1.1, J1.1
unnamed: J38.A5 (CC1), R3.2
unnamed: J38.B5 (CC2), R2.2
unnamed: Q5.1 (G), R8.2
unnamed: Q6.1 (G), R9.2
unnamed: Q11.1 (G), R10.2
unnamed: Q12.1 (G), R7.2
unnamed: Q13.1 (G), R6.2
unnamed: Q14.1 (G), R4.2
unnamed: Q15.1 (G), R5.2
unnamed: Q16.1 (G), R11.2
unnamed: Q17.1 (G), R12.2
unnamed: Q18.1 (G), R22.2
unnamed: R1.2, SW1.2, U1.94 (BOOT0)
unnamed: C9.1, U1.12 (PH0), Y2.1
unnamed: C10.1, U1.13 (PH1), Y2.2
unnamed: F2.1, U2.3 (VI)
unnamed: L1.1, U3.2 (OUT), U3.4 (FB)
unnamed: L2.1, U4.2 (OUT), U4.4 (FB)
unnamed: C7.2, U5.11 (CP)
unnamed: C8.2, U6.11 (CP)
unnamed: R15.1, U7.8 (Rs)
unnamed: R16.1, U7.5 (Vref)
unnamed: R13.1, U8.8 (Rs)
unnamed: R14.1, U8.5 (Vref)

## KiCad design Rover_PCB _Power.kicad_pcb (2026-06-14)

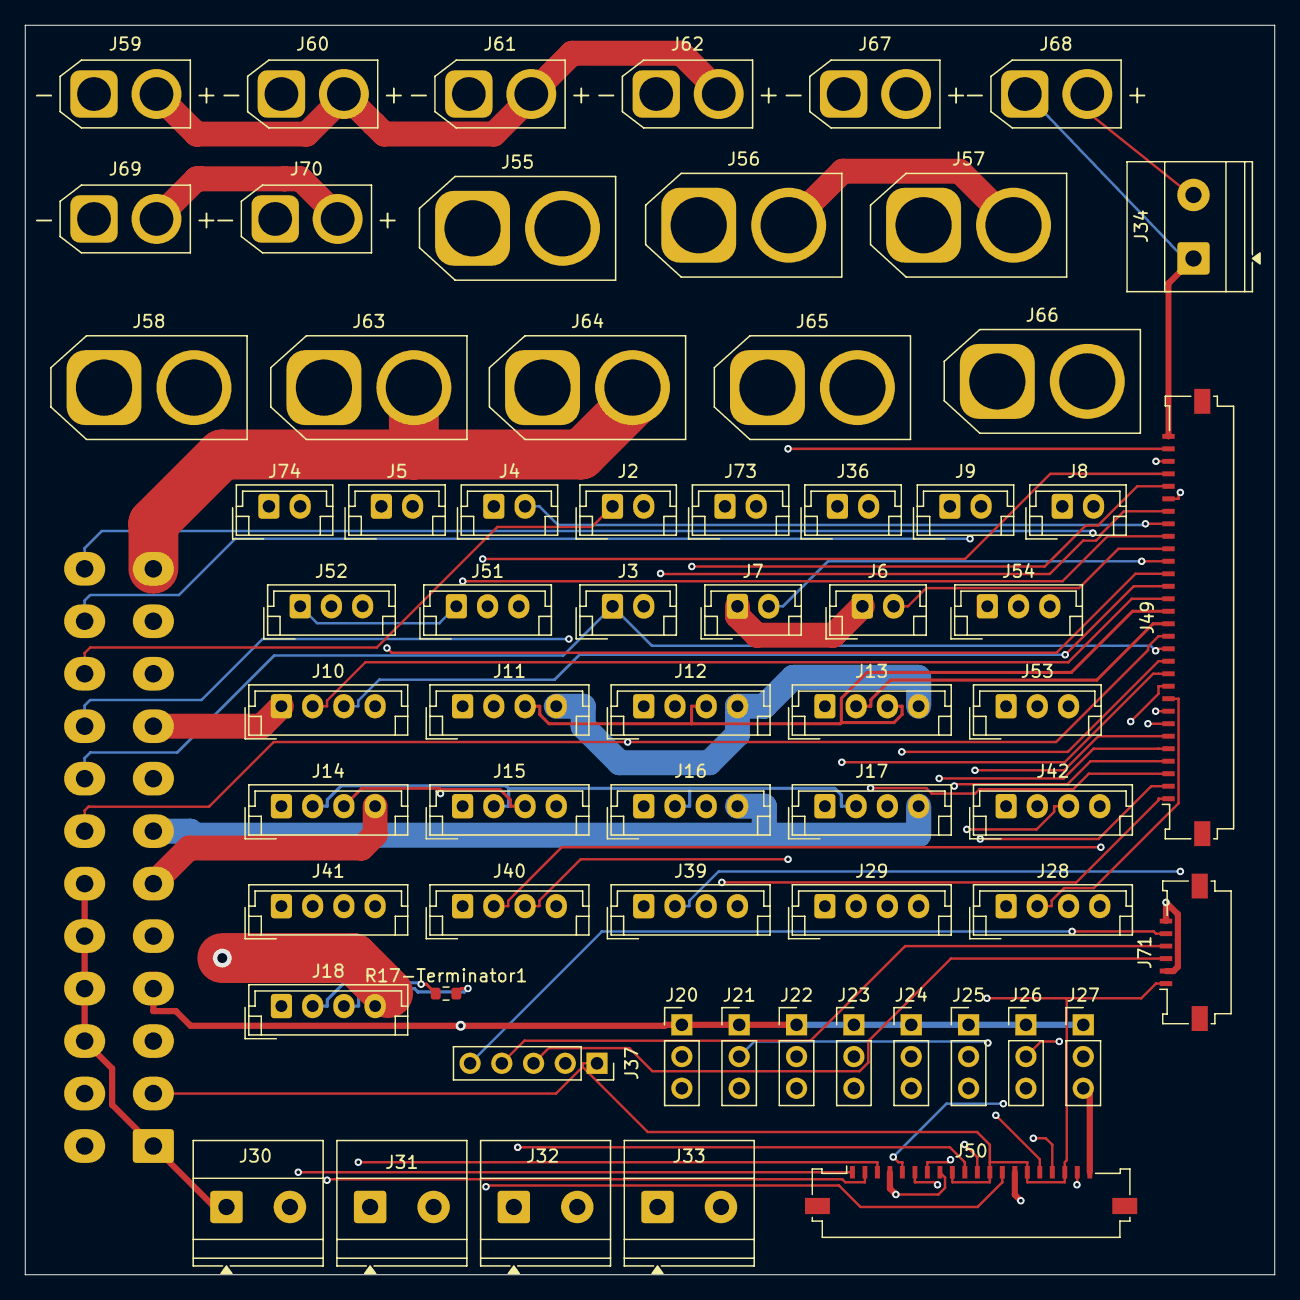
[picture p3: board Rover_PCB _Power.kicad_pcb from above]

Board: 4 copper layers, 100.0 x 100.0 mm, 65 parts (1 on the bottom side), 52 nets.

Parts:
J2: Brushed_Motor1; JST_EH_B2B-EH-A_1x02_P2.50mm_Vertical
J3: Brushed_Motor2; JST_EH_B2B-EH-A_1x02_P2.50mm_Vertical
J4, J5: LED_R_LR; JST_EH_B2B-EH-A_1x02_P2.50mm_Vertical
J6: LED_R_RR; JST_EH_B2B-EH-A_1x02_P2.50mm_Vertical
J7: LED_R_RL; JST_EH_B2B-EH-A_1x02_P2.50mm_Vertical
J8: LED_F_R; JST_EH_B2B-EH-A_1x02_P2.50mm_Vertical
J9: LED_F_L; JST_EH_B2B-EH-A_1x02_P2.50mm_Vertical
J10: LED_U_RGY; JST_EH_B4B-EH-A_1x04_P2.50mm_Vertical
J11: CAN_S1; JST_EH_B4B-EH-A_1x04_P2.50mm_Vertical
J12: CAN_S2; JST_EH_B4B-EH-A_1x04_P2.50mm_Vertical
J13: CAN_S3; JST_EH_B4B-EH-A_1x04_P2.50mm_Vertical
J14: CAN_S4; JST_EH_B4B-EH-A_1x04_P2.50mm_Vertical
J15: CAN_S5; JST_EH_B4B-EH-A_1x04_P2.50mm_Vertical
J16: CAN_S6; JST_EH_B4B-EH-A_1x04_P2.50mm_Vertical
J17: CAN7; JST_EH_B4B-EH-A_1x04_P2.50mm_Vertical
J18: CAN8; JST_EH_B4B-EH-A_1x04_P2.50mm_Vertical
J20: Servo1; PinHeader_1x03_P2.54mm_Vertical
J21: Servo2; PinHeader_1x03_P2.54mm_Vertical
J22: Servo3; PinHeader_1x03_P2.54mm_Vertical
J23: Servo4; PinHeader_1x03_P2.54mm_Vertical
J24: Servo5; PinHeader_1x03_P2.54mm_Vertical
J25: Servo6; PinHeader_1x03_P2.54mm_Vertical
J26: Servo7; PinHeader_1x03_P2.54mm_Vertical
J27: Servo8; PinHeader_1x03_P2.54mm_Vertical
J28: UART1; JST_EH_B4B-EH-A_1x04_P2.50mm_Vertical
J29: UART2; JST_EH_B4B-EH-A_1x04_P2.50mm_Vertical
J30: 3.3V; TerminalBlock_Phoenix_MKDS-1,5-2-5.08_1x02_P5.08mm_Horizont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
J31: 5V; TerminalBlock_Phoenix_MKDS-1,5-2-5.08_1x02_P5.08mm_Horizont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
J32: 12V; TerminalBlock_Phoenix_MKDS-1,5-2-5.08_1x02_P5.08mm_Horizont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
J33: 24V; TerminalBlock_Phoenix_MKDS-1,5-2-5.08_1x02_P5.08mm_Horizont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
J34: 48V; TerminalBlock_Phoenix_MKDS-1,5-2-5.08_1x02_P5.08mm_Horizont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
J36: Safety_Button; JST_EH_B2B-EH-A_1x02_P2.50mm_Vertical
J37: STLINK; PinSocket_1x05_P2.54mm_Vertical
J39: Load_Cell1; JST_EH_B4B-EH-A_1x04_P2.50mm_Vertical
J40: Load_Cell2; JST_EH_B4B-EH-A_1x04_P2.50mm_Vertical
J41: Load_Cell3; JST_EH_B4B-EH-A_1x04_P2.50mm_Vertical
J42: Load_Cell4; JST_EH_B4B-EH-A_1x04_P2.50mm_Vertical
J48: ATX; Molex_Mini-Fit_Jr_5566-24A_2x12_P4.20mm_Vertical
J49: Conn_01x30_Socket; Molex_200528-0300_1x30-1MP_P1.00mm_Horizontal
J50: FFC; Molex_200528-0200_1x20-1MP_P1.00mm_Horizontal
J51: NTC1; JST_EH_B3B-EH-A_1x03_P2.50mm_Vertical
J52: NTC2; JST_EH_B3B-EH-A_1x03_P2.50mm_Vertical
J53: NTC3; JST_EH_B3B-EH-A_1x03_P2.50mm_Vertical
J54: NTC4; JST_EH_B3B-EH-A_1x03_P2.50mm_Vertical
J55, J56, J57, J58: XT60_24V_OUT; AMASS_XT60-M_1x02_P7.20mm_Vertical
J59, J60, J61, J62: XT30_24V_OUT; AMASS_XT30U-F_1x02_P5.0mm_Vertical
J63, J64: XT60_48V_OUT; AMASS_XT60-M_1x02_P7.20mm_Vertical
J65, J66: XT60_12V_OUT; AMASS_XT60-M_1x02_P7.20mm_Vertical
J67, J68: XT30_48V_OUT; AMASS_XT30U-F_1x02_P5.0mm_Vertical
J69, J70: XT30_12V_OUT; AMASS_XT30U-F_1x02_P5.0mm_Vertical
J71: FFC; Molex_200528-0060_1x06-1MP_P1.00mm_Horizontal
J73: BAT1; JST_EH_B2B-EH-A_1x02_P2.50mm_Vertical
J74: BAT_TOTAL; JST_EH_B2B-EH-A_1x02_P2.50mm_Vertical
R17-Terminator1: 120; R_0603_1608Metric

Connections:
/+3.3V: J30.2, J37.1, J48.2, J48.3, J50.9, J50.12, J50.15, J50.18, J51.1, J52.1, J53.1, J54.1, J71.1
/+5V: J20.1, J21.1, J22.1, J23.1, J24.1, J25.1, J26.1, J27.1, J28.4, J29.4, J31.2, J48.4
/+12V: J4.1, J5.1, J6.1, J7.1, J8.1, J9.1, J11.4, J12.4, J13.4, J14.4, J15.4, J32.2, J48.5, J48.6, J65.2, J66.2, J69.2, J70.2
/+24V: J10.1, J16.4, J17.4, J33.2, J48.7, J48.8, J48.9, J55.2, J56.2, J57.2, J58.2, J59.2, J60.2, J61.2, J62.2
/+48V: J18.4, J34.2, J48.10, J48.11, J48.12, J48.13, J48.14, J63.2, J64.2, J67.2, J68.2
/AVDD: J39.1, J49.24
/AVDD1: J40.1, J49.27
/AVDD2: J41.1, J50.1
/AVDD3: J42.1, J50.5
/CANH: J11.2, J12.2, J13.2, J14.2, J15.2, J16.2, J17.2, J18.2, J49.15, R17-Terminator1.1
/CANL: J11.3, J12.3, J13.3, J14.3, J15.3, J16.3, J17.3, J18.3, J49.16, R17-Terminator1.2
/GND: J11.1, J12.1, J13.1, J14.1, J15.1, J16.1, J17.1, J18.1, J20.3, J21.3, J22.3, J23.3, J24.3, J25.3, J26.3, J27.3, J28.1, J29.1, J30.1, J31.1, J32.1, J33.1, J34.1, J36.1, J37.2, J39.4, J40.4, J41.4, J42.4, J48.1, J48.15, J48.16, J48.17, J48.18, J49.30, J50.4, J50.8, J50.11, J50.14, J50.17, J50.20, J51.3, J52.3, J53.3, J54.3, J55.1, J56.1, J57.1, J58.1, J59.1, J60.1, J61.1, J62.1, J63.1, J64.1, J65.1, J66.1, J67.1, J68.1, J69.1, J70.1, J71.2, J71.6, J73.2, J74.2
/INA1+: J40.3, J49.29
/INA1-: J40.2, J49.28
/INA2+: J41.3, J50.3
/INA2-: J41.2, J50.2
/INA3+: J42.3, J50.7
/INA3-: J42.2, J50.6
/INA+: J39.2, J49.25
/INA-: J39.3, J49.26
/NRST: J37.5, J71.5
/OUTA1: J2.1, J48.22
/OUTA2: J3.1, J48.20, J49.13
/OUTB1: J2.2, J48.21
/OUTB2: J3.2, J48.19, J49.14
/PA6: J26.2, J49.7
/PA7: J27.2, J49.8
/PB0: J4.2, J49.23
/PB1: J5.2, J49.22
/PB5: J6.2, J49.21
/PB8: J7.2, J49.20
/PB9: J8.2, J48.24
/PC0: J50.10, J51.2
/PC1: J50.13, J52.2
/PC2: J50.16, J53.2
/PC3: J50.19, J54.2
/PC6: J9.2, J48.23
/PC7: J10.2, J49.17
/PC8: J10.3, J49.18
/PC9: J10.4, J49.19
/PD14: J24.2, J49.5
/PD15: J25.2, J49.6
/PE9: J20.2, J49.1
/PE11: J21.2, J49.2
/PE13: J22.2, J49.3
/PE14: J23.2, J49.4
/RX1: J28.3, J49.10
/RX2: J29.3, J49.12
/SWCLK: J37.4, J71.4
/SWDIO: J37.3, J71.3
/TX1: J28.2, J49.9
/TX2: J29.2, J49.11

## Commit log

2026-06-02 Projekt PCB dla Łazika (Rover-PCB) - Podział na 2 płytki (Główna i Zasilania)
    [Rover_PCB _Power.kicad_pcb, Rover_PCB.kicad_pcb, Rover_PCB.kicad_sch]
2026-06-14 Aktualizacja schematu i PCB: dodanie rezonatora Y2, kondensatorow C9/C10 i punktow testowych J75-J79 oraz aktualizacja README.md i .gitignore
    [Rover_PCB.kicad_pcb, Rover_PCB.kicad_sch]
2026-06-14 Aktualizacja README.md: dodanie parametrow fizycznych PCB, ulozenia warstw i klas netow
2026-06-14 Usuniecie punktow testowych J75-J79 z tabeli BOM w README.md
2026-06-14 Aktualizacja plytki zasilania (Power), uaktualnienie README.md o szczegoly klas netow i grubosci sciezek na obu plytkach
    [Rover_PCB _Power.kicad_pcb, Rover_PCB.kicad_pcb]
